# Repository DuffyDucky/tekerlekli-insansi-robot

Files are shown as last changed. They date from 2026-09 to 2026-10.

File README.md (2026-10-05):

# Tekerlekli insansı robot — üniversite projesi

Manisa Celal Bayar Üniversitesi Mekatronik MYO'da 4 kişilik ekiple yapılacak, bacaksız, tekerlekle
hareket eden, gövde + kafa + 2 kollu insansı robot. Bu klasör projenin tek çalışma alanı: raporlar,
planlama, tasarım (CAD) ve ileride yazılım kodu burada tutulur.

## Klasör yapısı

| Klasör / dosya | İçerik |
|---|---|
| `raporlar/Humanoid-Robot-Fizibilite-Raporu.html` | Fizibilite raporu: maliyet, ses mi görüntü mü, yetkinlik, teknik gereklilikler, profesyonel destek, takvim, finansman, riskler |
| `raporlar/kaynaklar/` | Raporun dayandığı araştırma notları (donanım/maliyet, yazılım/yapay zekâ, referans projeler/finansman, parça ölçüleri, fiyat araştırması ve doğrulaması) |
| `planlama/proje-plani.md` | Kapsam, takvim, roller, ilk iki hafta, riskler, açık sorular |
| `planlama/maliyet.json` | Doğrulanmış malzeme maliyeti (satıcı, TL, bağlantı, stok); demodaki maliyet bölümünün tek kaynağı |
| `tasarim/Robot-Tasarim-Demosu.html` | Gerçek parçalarla 3B CAD montajı; V1 / V2 düğmesi; devrilme, motor ve servo hesabı canlı; TL + USD proje maliyeti |
| `tasarim/cad/Humanoid-Robot-Montaj.step` · `-V2` · `-V3` | SolidWorks'te açılan montaj dosyaları (V1, V2, V3) |
| `tasarim/cad/parca-listesi.csv` · `-V2` · `-V3` | Gerçek parça listesi (model, ölçü, adet, kütle) |
| `tasarim/cad/robot_cad.py` | Modeli üreten kod (STEP + CSV + demo) |
| `tasarim/cad/demo_uret.py` | Demoyu şablon + model + maliyetten yeniden üretir; CadQuery gerekmez |
| `CLAUDE.md` | Bu klasörde açılan yapay zekâ oturumları için bağlam |

HTML dosyaları çift tıklayınca tarayıcıda açılır. Demodaki 3B görünüm için internet gerekir.

## Proje çerçevesi (Duffy, 26 Eylül 2026)

- Ekip: **4 kişi**
- Süre: **normalde 1 dönem**, proje başarılı giderse muhtemelen 2 dönem
- Bütçe: **okul / hoca destekli**
- Karar verilmemiş: robot yalnız sesle mi etkileşsin, ses + görüntüyle mi

## Şu ana kadarki kararlar ve öneriler

| Konu | Öneri / sonuç |
|---|---|
| Ses mi görüntü mü | Önce ses + tekerlek + kayıtlı jestler. İkinci adım "hafif görüntü": yüzü algılayıp kafayı kişiye çevirme ve düğmeyle "ne görüyorsun?". Yüz **tanıma**, otonom gezinme (ROS 2 / Nav2), eşya tutan kol kapsam dışı. |
| Konuşma zinciri | Bulut konuşma tanıma (Türkçe) + bulut dil modeli + seslendirme; uyandırma kelimesi yerine bas-konuş düğmesi; internet kesilirse çevrimdışı yedek mod |
| Bütçe | CAD tasarımının doğrulanmış malzeme listesi (27 Eylül 2026): **≈ 64.500 TL ≈ 1.320 USD** (%15 pay, yedek parça ve kargo dahil); 54 kalemin 48'i satıcı sayfasından doğrulandı. Baskı hizmetiyle ≈ 68.800 TL. Aylık bulut ≈ 10–20 $. (Fizibilite tahmini ≈ 61.700 TL'ydi.) |
| Ekip | Yazılım / yapay zekâ sorumlusu şart; güç elektroniği ve KVKK için danışman |
| Güvenlik | LiPo yerine LiFePO4 akü, donanımsal acil stop, servo ve işlemci için ayrı güç hatları |
| Mekanik | Ağırlığı alta topla, tabanı geniş tut, robotu kat kat kur ve her katta test et |
| V2 (hoca, 2 Ekim 2026) | 10,1" dokunmatik ekran göğüste, kafada iki yuvarlak göz ekranı (Pepper benzeri; Duffy A seçeneğini seçti). Tekerlekler yerinde, taban kabuğu genişleyip onları sarıyor. Malzeme ≈ 77.900 TL (%15 pay dahil; V1 64.500). |
| V3 deneme (Duffy, 2 Ekim 2026) | V2 yorumu: "taban çok geniş", "ekran çok alçakta", "yüz ifadesi çok ruhsuz". V3: boy 125 cm, şase 27 cm (akünün sığdığı en dar), taban 44 cm ve yukarı 30 cm'ye daralan etek, 10,1" ekran üst göğüste 15° yukarı eğik (merkez 82 cm), kafada 7" yüz ekranı + siyah akrilik yüz paneli (Pi 5 iki HDMI). Malzeme ≈ 79.400 TL. |

## CAD modelinden çıkanlar (varsayılan tasarım)

| Konu | Sonuç |
|---|---|
| Ölçü | 48 × 52 × 115 cm (teker dahil genişlik × derinlik × boy) |
| Toplam kütle | 17,75 kg (0,6 kg vida/kablo payı dahil) |
| En ağır kalemler | 40×40 ağır sigma ≈ 5,3 kg · LiFePO4 akü 2,8 kg · PETG kabuklar ≈ 3,3 kg · alt plaka 1,3 kg |
| Ağırlık merkezi | yerden 291 mm, merkezin 17 mm gerisinde |
| Devrilme | ileri frende 6,8, geri frende 5,7 m/s² (acil stop payı 3,8×); yana 7,2 m/s² |
| Taban motoru | 4× JGB37, 5° rampada motor başına 4,7 kg·cm (sürekli sınırın %74'ü) |
| Kol | 386 g; omuz 5,4 kg·cm (DS3218 güvenli sınır 10), dirsek 1,0 kg·cm (MG996R sınır 5) |
| **V2 farkı** | Ölçü 51 × 52 × 115 cm · 18,9 kg · ağırlık merkezi 282 mm · devrilme ileri 6,9, geri 5,9 m/s² (pay 4,0×), yana 7,4 · motor 5,0 kg·cm (%79) · PETG ≈ 4,4 kg · taban kabuğu 513 × 227 × 520 (9 baskı parçası), gövde 6, kafa 2 · çakışma yok (kol × gövde 2.822 mm³ V1'den kalma) |
| **V3 farkı** | Ölçü 44 × 52 × 125 cm · 18,6 kg · ağırlık merkezi 337 mm · devrilme ileri 5,8, geri 5,0 m/s² (pay 3,3×), yana 5,2 (3,4×) · motor 4,9 kg·cm (%77) · PETG ≈ 4,4 kg · etek 6, gövde 8, kafa 2 baskı parçası · çakışma yok (kol × gövde 2.299 mm³, V1'den kalma sorun) |
| Yapı | 340×500 sigma çerçeve; altta 3 mm Al plaka + yatık akü (arka) + motor sürücüleri (ön); 40 mm burç üstünde 5 mm kontrplak elektronik katı; motorlar L braketle plaka altında; tek sigma direk + 200 mm omuz traversi; PETG kabuklar |

## Konuşma geçmişi (26 Eylül 2026)

1. **Fizibilite araştırması:** üç paralel araştırma (donanım-maliyet, yazılım-yapay zekâ, referans
   projeler-finansman-destek) → `raporlar/`. Ajan çıktılarında iki düzeltme yapıldı: 2 JGB37 motor
   15–20 kg'a yetmez (≤15 kg ya da 4 motor); LiPo yerine LiFePO4.
2. **Fiziksel yapı endişesi:** Duffy: "beni korkutan fiziksel yapısı". Yaklaşım: robot aslında
   "insan gibi görünen bir servis arabası"; ağırlık alta, katman katman yapım ve test.
3. **Tasarım demosu v1:** basit kutularla 3B model, kaydırıcılarla devrilme/motor/servo hesabı.
4. **Gerçek parçalarla CAD (v2):** Duffy: "buna reel bir görünüm kazandır kullanacağın parçalar
   gerçek olsun hatta solid gibi bir yerde çiz". Bilgisayarda CAD programı olmadığı için CadQuery
   ile gerçek ölçülü montaj kuruldu; 19 parçanın ölçüsü araştırıldı (12'si üretici çiziminden) →
   `raporlar/kaynaklar/04-parca-olculeri.md`. STEP dosyası geri okuma testinden geçti (218 geçerli katı).
5. **Taşıma:** proje DuffyOS vault'undan bu klasöre taşındı; bundan sonraki çalışmalar burada.

## Açık işler

- [ ] Robotun amacını hocayla netleştir (karşılama / tanıtım / rehber) → kapsam ve malzeme listesi kesinleşir
- [ ] İşletmede Mesleki Eğitim (4. yarıyıl, 2027 bahar) projenin 2. dönemini daraltır mı? Bölüme sor
- [ ] Rolleri yaz; yazılım sorumlusu yoksa bilgisayar mühendisliğinden ortak ara
- [ ] Bölümde hazır malzemeyi listele (3D yazıcı, dizüstü, profil, güç kaynağı)
- [ ] Siparişi erken ver: 27 Eylül'de enkoderli JGB37 yalnız Direnc.net'te stokta; Camera Module 3 Türkiye'de hiçbir satıcıda yok (stok alarmı ya da Adafruit)
- [ ] Limacell 24 Ah akünün ölçüsünü satıcıya sor (CAD yuvası 181 × 77 × 167 mm)
- [ ] Lazer kesim (Al plaka, kontrplak) için DXF ile online teklif al; tahmini 2.000 TL
- [ ] JGB37 braketini alırken delik düzenini kontrol et (mil 7 mm kaçık; çoğu satıcı ortalı mil braketi satıyor)
- [ ] STEP dosyasını SolidWorks'te aç (henüz denenmedi)
- [ ] Parçalar gelince tahmini ölçüleri kumpasla doğrula (enkoder boyu, braket delikleri, BTS7960 delikleri)
- [ ] Ağırlık için hafif profil (40×40 hafif veya 30×30) seçeneğini değerlendir (≈ 2 kg, tahmini)
- [x] Hoca geri bildirimi (2 Ekim 2026): (1) ekran daha büyük olsun (şu an 7"); (2) tekerlekler dışarıda
  değil, kabuğun içine gömülü olsun. Hoca: ekran gövdede de olabilir. Karar (Duffy): tekerlekler yerinde kalır,
  kabuk dışa genişleyip tekerlekleri sarar; yüz A seçeneği (göğüste ekran + kafada göz ekranları). → Demoda V2.
  SolidWorks tasarımında da uygulanacak.
- [ ] V2 kabuklarının 23 cm'lik baskı bölme çizgileri ve birleşme yerleri (SolidWorks'te)
- [ ] 10,1" ekranın 5 V ≈ 0,75 A beslemesini güç planına ekle; ekran ve göz ekranı kütlelerini tartıp CAD'e gir
- [ ] Okulun 3D yazıcı tablası 25 × 25 × 25 cm (hocanın söylediği; model doğrulanmadı). Her baskı parçası
  buna sığacak şekilde bölünmeli (pay için ≤ 23 cm hedef)

## CAD'i yeniden üretme

`tasarim/cad/robot_cad.py` başındaki ölçü ve yerleşim değerleri değiştirilip çalıştırılınca STEP,
parça listesi ve demo birlikte yenilenir. Python 3.12 + CadQuery 2.8 gerekir (`requirements.txt`).
Sanal ortamı OneDrive dışında kur (yüzlerce MB):

```powershell
uv venv --python 3.12 $env:LOCALAPPDATA\robot-cad-venv
uv pip install --python $env:LOCALAPPDATA\robot-cad-venv\Scripts\python.exe -r tasarim\cad\requirements.txt
cd tasarim\cad
& $env:LOCALAPPDATA\robot-cad-venv\Scripts\python.exe robot_cad.py . model.json
```

Koordinatlar SolidWorks ile aynı: Y yukarı, Z ileri (robotun yüzü +Z), X sağ-sol, birim mm.

Yalnız fiyat ya da demo arayüzü değiştiyse CadQuery gerekmez: `planlama/maliyet.json` veya
`tasarim/cad/viewer-template.html` düzenlendikten sonra `python tasarim\cad\demo_uret.py` demoyu yeniler
(3B modeli mevcut demodan alır).

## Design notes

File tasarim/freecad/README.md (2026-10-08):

# FreeCAD modelleri (V3)

Robotun FreeCAD 1.1 modeli modül modül kuruluyor. Her modül kendi klasöründe, Python betikleriyle üretiliyor.
Üretilmiş dosyaları (FCStd, STEP, JSON, görseller, rapor.html) elle düzenleme; betiği değiştirip yeniden çalıştır.
Eski CadQuery modeli `tasarim/cad/robot_cad.py` yalnız ölçü kaynağı olarak okunuyor.

## Klasör düzeni

| Dosya / klasör | Rol |
|---|---|
| `arayuz.py` | **Tek ölçü ve arayüz kaynağı** (saf Python, FreeCAD'siz import edilir): global koordinat, V3 ana ölçüleri (robot_cad satırıyla), sigma profil özellikleri, cıvata/pul/somun/çekiç somun tabloları, köşe bağlantı ölçüleri, modül yerleşimleri (`MODULLER`), ayrılmış bölgeler (`BOLGELER`) |
| `ortak_lib.py` | Ortak parça kütüphanesi: `box/cyl/hexprism`, DIN 912/913/934/985/125, ısıl gömme somun, çekiç somun, rulman, sigma (X/Y/Z), 40×40 geniş köşe bağlantı, iç köşe bağlantı, `yerlestir()` |
| `sigma_profil.py` | 40×40 ağır sigma kesiti (kesit alanı üreticiye göre doğrulandı); doğrudan çalışınca test parçası üretir |
| `omuz/` | Sağ omuz (2 eksen): `omuz_parcalar.py` parçalar + kinematik, `omuz_montaj.py` kontroller + kayıt, `omuz_gorsel.py`, `omuz_rapor.py`, `omuz_regresyon.py` |
| `iskelet/` | Şase çerçevesi + gövde direği + omuz traversi + bağlantılar: `iskelet_parcalar.py`, `iskelet_montaj.py`, `iskelet_gorsel.py`, `iskelet_rapor.py` → `rapor.html`, `iskelet_regresyon.py` |
| `kabuk/` | Gövde kabuğu + taban eteği + Nextion göğüs ekranı + iskelete bağlantı braketleri: `kabuk_lib.py`, `kabuk_parcalar.py`, `kabuk_montaj.py` (kontroller, baskı analizi), `kabuk_gorsel.py`, `kabuk_rapor.py` → `rapor.html` |
| `dirsek/` | Sağ dirsek + ön kol + bilek + el (sol = X aynası): `dirsek_lib.py` (MG996R, horn, baskı analizi), `dirsek_parcalar.py`, `dirsek_montaj.py` (kontroller, dirsek içi tarama, tork, baskı), `dirsek_gorsel.py`, `dirsek_rapor.py` → `rapor.html`, `dirsek-analiz.json`. Arayüz `arayuz.DIRSEK`; modüller arası tarama `carpisma.py` (kol zinciri), ana montajda `dirsek_sag` / `dirsek_sol` |
| `kafa/` | Boyun + pan + tilt + kafa: `kafa_lib.py` (6808-2RS, 7" LCD, Camera Module 3, baskı analizi), `kafa_parcalar.py`, `kafa_montaj.py` (kontroller, pan × tilt tarama, R62 uyumu, tork, baskı), `kafa_gorsel.py`, `kafa_rapor.py` → `rapor.html`, `kafa-analiz.json`. Arayüz `arayuz.KAFA`, `MODULLER['kafa']`; modüller arası tarama `carpisma.py` bölüm 4b, ana montajda `kafa` (pan + tilt) |
| `taban/` | Alt plaka + elektronik katı (ön) + güç paneli (arka) + 4 motorlu tahrik + akü + güç elektroniği + kartlar + sonar + acil stop: `taban_lib.py`, `taban_parcalar.py`, `taban_montaj.py` (kontroller, iskelet/kabuk statik tarama, devrilme/motor/akü hesabı, DXF, baskı) → `taban-analiz.json`, `dxf/`; `taban_gorsel.py`, `taban_rapor.py` → `rapor.html`. Arayüz `arayuz.TABAN`, `MODULLER['taban']`; modüller arası tarama `carpisma.py` bölüm 4c, ana montajda `taban` (4 teker eklemi) |
| `montaj/` | **Ana montaj** (FreeCAD Assembly): iskelet + sağ/sol omuz + kabuk + sağ/sol dirsek + kafa + taban (tam robot) tek dosyada (sol = gerçek aynalı geometri), eklemler, eklem doğrulaması → `robot-montaj.FCStd`, `rapor.html` |
| `carpisma.py` | Modüller arası çakışma: modülleri `arayuz.MODULLER` ile yerleştirir, ev pozunu, hareketli modüllerin tüm tarama pozlarını, kol zincirini (omuz × dirsek × bilek; iki kol birbirine karşı), kafayı (pan × tilt × iki kolun pozları), tabanı (ev pozu, iki kolun tüm pozları, kafa) ve henüz çizilmemiş modüllerin ayrılmış bölgelerini (artık yok) tarar. **Bölümlü:** `CARPISMA_BOLUM` ile bölüm seçilir, her bölüm `carpisma-bolum/<bolum>.json`'a yazar |
| `carpisma_kos.py` | Bölümlü koşu sürücüsü (sistem Python'u): bölümleri sırayla ayrı `freecadcmd` süreçlerinde koşar (bellek her bölümden sonra boşalır), sonunda birleştirir → `carpisma-sonuc.json` (`bolumler`: süre, tepe bellek; `birlestirme_notu`, `tek_kosu`) |
| `OZET.md` | Tüm robotun tek sayfalık özeti: modüller, sayılar, kütle/AM, devrilme, motor, akü, yazılım sınırları, açık işler |

Koordinat (global): orijin zemin + robot merkezi, +X robotun sağı, +Y yukarı, +Z ileri (yüz), mm.
Her modülün yerel orijini `arayuz.MODULLER`'de (sağ omuz = travers merkezi (0, 955, 0); sol omuz = sağın X aynası).

## Çalıştırma

`freecadcmd`, yolunda "ü" (Masaüstü) olan betiği doğrudan alınca çöküyor. Betikler ASCII yoldaki başlatıcıyla çalışır
(`C:\Users\Victus\.robot-cad\run_fc.py`, hedef betik `FC_SCRIPT` ortam değişkeninde). Konsol çıktısı ASCII.

```bash
FC="$LOCALAPPDATA/Programs/FreeCAD 1.1/bin/freecadcmd.exe"   # GUI gerektirenler için freecad.exe
R="C:/Users/Victus/OneDrive/Masaüstü/Robot/tasarim/freecad"
L=C:/Users/Victus/.robot-cad/run_fc.py

# iskelet: montaj + kontroller + eğilme + STEP/BOM/JSON (~15 s), görseller (GUI), rapor (sistem Python'u)
FC_SCRIPT=$R/iskelet/iskelet_montaj.py "$FC" $L
FC_SCRIPT=$R/iskelet/iskelet_gorsel.py "$LOCALAPPDATA/Programs/FreeCAD 1.1/bin/freecad.exe" $L
python $R/carpisma_kos.py                             # modüller arası tarama: 9 bölüm sırayla, ayrı süreçlerde (~1,5 saat) -> carpisma-sonuc.json
python $R/carpisma_kos.py kafa_sag kafa_sol           # yalnız seçilen bölümler + birleştirme (diğerleri eski dosyalarından; not 'tek_kosu: false')
python $R/carpisma_kos.py birlestir                   # yalnız birleştirme (carpisma-bolum/*.json -> carpisma-sonuc.json)
FC_SCRIPT=$R/carpisma.py CARPISMA_BOLUM=taban "$FC" $L   # tek bölüm elle (statik|omuz|kol_sag|kol_sol|kolkol|kafa_sabit|kafa_sag|kafa_sol|taban;
                                                         # kol, kafa, hepsi kısaltmaları); günlükler %TEMP%/carpisma-<bolum>.log
# CARPISMA_KISA=1: kafa x kol taramasını yasak bölge çevresine daraltan geliştirme testi (carpisma-bolum/<bolum>-kisa.json, birleştirmeye girmez)
python $R/iskelet/iskelet_rapor.py                     # iskelet/rapor.html

# omuz: montaj + tarama + tork (~40 s), görseller, rapor
FC_SCRIPT=$R/omuz/omuz_montaj.py "$FC" $L
FC_SCRIPT=$R/omuz/omuz_gorsel.py "$LOCALAPPDATA/Programs/FreeCAD 1.1/bin/freecad.exe" $L
python $R/omuz/omuz_rapor.py

# omuz regresyonu: ortak dosyalar (arayuz, ortak_lib, sigma_profil) değişince omuzun aynı kaldığını kanıtlar
FC_SCRIPT=$R/omuz/omuz_regresyon.py REG_ETIKET=sonra "$FC" $L   # omuz/regresyon/once.json ile karşılaştırır -> fark.json
# iskelet regresyonu (dosya yazmaz, yalnız iskelet_parcalar'ı import eder): değişiklikten önce once, sonra sonra
FC_SCRIPT=$R/iskelet/iskelet_regresyon.py REG_ETIKET=sonra "$FC" $L   # iskelet/regresyon/fark.json

# kabuk: parçalar + kontroller + baskı analizi + STEP/BOM/JSON (~6 dk), görseller (GUI), rapor
FC_SCRIPT=$R/kabuk/kabuk_montaj.py "$FC" $L
FC_SCRIPT=$R/kabuk/kabuk_gorsel.py "$LOCALAPPDATA/Programs/FreeCAD 1.1/bin/freecad.exe" $L
python $R/kabuk/kabuk_rapor.py                 # carpisma.py ve ana montajdan sonra (onların sonuçlarını da okur)
# dirsek: montaj + kontroller + tarama + tork + baski (~30 s), gorseller (GUI), rapor
FC_SCRIPT=$R/dirsek/dirsek_montaj.py "$FC" $L
FC_SCRIPT=$R/dirsek/dirsek_gorsel.py "$LOCALAPPDATA/Programs/FreeCAD 1.1/bin/freecad.exe" $L
python $R/dirsek/dirsek_rapor.py
# kafa: montaj + kontroller + pan x tilt tarama + tork + baski (~2 dk), gorseller (GUI), rapor
FC_SCRIPT=$R/kafa/kafa_montaj.py "$FC" $L
FC_SCRIPT=$R/kafa/kafa_gorsel.py "$LOCALAPPDATA/Programs/FreeCAD 1.1/bin/freecad.exe" $L
python $R/kafa/kafa_rapor.py
# taban: parcalar + kontroller + iskelet/kabuk statik tarama + hesaplar + DXF + baski (~2 dk), gorseller (GUI), rapor
FC_SCRIPT=$R/taban/taban_montaj.py "$FC" $L
FC_SCRIPT=$R/taban/taban_gorsel.py "$LOCALAPPDATA/Programs/FreeCAD 1.1/bin/freecad.exe" $L
python $R/taban/taban_rapor.py
```

Not: `omuz_regresyon.py` `omuz_montaj.py`'yi çalıştırıp omuz çıktılarını yeniden yazar (FCStd GUI durumu kaybolur). Sonuç birebir
aynıysa üretilmiş omuz dosyaları `git checkout` ile geri alınabilir.

PowerShell'de: `$env:FC_SCRIPT="<betik>"; & "$env:LOCALAPPDATA\Programs\FreeCAD 1.1\bin\freecadcmd.exe" C:\Users\Victus\.robot-cad\run_fc.py`

Sıra: `arayuz.py` veya `ortak_lib.py` değişirse → omuz ve iskelet regresyonu → iskelet montajı → kabuk montajı → dirsek montajı → `carpisma.py` →
`carpisma_kos.py` → ana montaj (`ana_montaj.py` + `montaj_gorsel.py` + `montaj_gui_kontrol.py` + `eklem_dogrulama.py`) → görseller → raporlar
(`montaj_rapor.py`, `taban_rapor.py`, `kafa_rapor.py`, `kabuk_rapor.py`, `dirsek_rapor.py`; hepsi `carpisma-sonuc.json` ve montaj çıktılarını okur).

## Ana montaj (`montaj/`)

Tüm modüller tek FreeCAD Assembly dosyasında: `robot-montaj.FCStd` (+ `robot-montaj.step`). Modül listesi ve yükleyiciler
`montaj/moduller.py`'de (`SIRA` + `MODUL_YUKLE`); yerleşim yalnız `arayuz.MODULLER`'den okunur, sol omuz şekil aynalanarak
(gerçek aynalı geometri, parça adları "(sol)") kurulur; sol dirsek de aynı yolla. Eklemler: iskelet zemine sabit, her omuz gövdesi ve kabuk iskelete sabit, her omuzda
öne-arka (S1, −45…135°) ve yana açma (S2, 0…120°) döner eklemi. Her dirsek çatalı omuzun Kol grubuna sabit
(üst kol tüpü ucu), her kolda dirsek (0…105°) ve bilek (−90…90°) döner eklemi; eksen ve sınırlar `dirsek/dirsek-montaj.FCStd`'den okunup
`arayuz.DIRSEK` ile karşılaştırılır. Kafanın sabit boynu (Kafa_Govde) traverse sabit; pan (Kafa_Govde → Kafa_Boyun, −90…90°) ve tilt
(Kafa_Boyun → Kafa_Bas, −25…30°) döner eklemleri `kafa/kafa-montaj.FCStd`'den (etiketle: dosyada pan eklemi "Pan001") okunup `arayuz.KAFA` ile
karşılaştırılır; kablo demeti gösterimi ana montajda yok. Dirsek yükleyicisinde `ust_kol` (zincir: beklenen poz omuz açılarını da alır) ve `analiz` (analiz JSON yolu) var. Eksen ve sınırlar `omuz/omuz-montaj.FCStd`'den okunur.

```bash
M=$R/montaj
FC_SCRIPT=$M/ana_montaj.py "$FC" $L          # montaj + STEP + montaj-analiz.json (parça/kütle/AM modül toplamıyla karşılaştırılır)
FC_SCRIPT=$M/montaj_gorsel.py "$LOCALAPPDATA/Programs/FreeCAD 1.1/bin/freecad.exe" $L   # eklem görünümleri + Kollari_oynat simülasyonu, dosyayı GUI'den kaydeder; görseller; GIF kareleri %TEMP%/robot-montaj-kare
FC_SCRIPT=$M/montaj_gui_kontrol.py "$LOCALAPPDATA/Programs/FreeCAD 1.1/bin/freecad.exe" $L   # taze açılış: eklem görünür/seçilebilir, fareyle sürükleme -> gui-kontrol.json
FC_SCRIPT=$M/eklem_dogrulama.py "$FC" $L      # eklemleri simülasyonla sürer, omuz kinematiğiyle karşılaştırır -> eklem-dogrulama.json
python $M/montaj_rapor.py                      # GIF + montaj/rapor.html
```

- `ana_montaj.py` tek başına çalışırsa dosyada eklem görünüm nesneleri olmaz; ardından `montaj_gorsel.py` şart.
- FreeCAD 1.1'de eklem sınırları yalnız fareyle sürüklemede uygulanır; simülasyon ve `solve()` sınır dışı açıyı kabul eder.
- Ana montajda bir parçanın şekli kendi Placement'ını taşıyabilir (kafa parçaları): dosyadan AM hesabında yalnız üst grubun yerleşimi uygulanır.
- Taban: gövde grubu (`Taban_Govde`) uzun raya sabit; 4 teker grubu (`Taban_OnSagTeker` …: teker + kaplin + M4 eksenel vida + pul)
  gövdeye **sınırsız** döner eklemle (`Taban_TekerOnSag` …; eksen motor mili +X, teker merkezi x ±178, y 62,5, z ±185; pozitif = ileri
  yuvarlanma). `taban-montaj.FCStd`'de eklem yok; eksen `taban_parcalar` (X_WH, Z_WH, arayuz.AX) ile `moduller.yukle_taban`'da kurulur.
  Grup adları eklem adlarıyla çakışmamalı (FreeCAD aynı adlı nesneye "001" ekler).
- Yeni modül: `arayuz.MODULLER`'e yerleşim, `moduller.py`'ye yükleyici (parçalar, gruplar, bağlantı, eklemler (sınır `None` = sınırsız),
  beklenen poz) ve `SIRA`'ya ad. Hareketli modülün beklenen pozu `eklem_dogrulama.py`'de karşılaştırılır.

## Kontroller

| Kontrol | Nerede | Ölçüt |
|---|---|---|
| Parça geçerliliği | her `*_montaj.py` | `isValid()` ve tek katı |
| Modül içi çakışma | her `*_montaj.py` | tüm çiftler, `common().Volume > 0,5 mm³` çakışma |
| Bağlantı oturması | `iskelet_montaj.py` | köşe bağlantı ve kama profile dayalı, çekiç somun dudak altında, cıvata ucu somunu geçip kanal tabanına değmiyor, set vida tabana dayalı |
| Ayrılmış bölgeler | `iskelet_montaj.py`, `carpisma.py` | henüz çizilmemiş modüllerin bölgelerine taşma yok |
| Modüller arası | `carpisma.py` (bölümlü, `carpisma_kos.py`) | ev pozu + her hareketli modülün tüm tarama pozları; kol zinciri (omuz −45…135 / 0…120 × dirsek 0…105 × bilek ±90, kaba 15° + 5 mm altında ince 5°, aralık dışı halka ayrı) iskelet, kabuk, bölgeler, omuz gövde/göbeğine karşı; iki kol birbirine karşı (simetrik, zıt, birlikte öne); kafa (pan −180…165 × tilt −25…40, kaba 15°) sabit modüllere ve iki kolun 1770'er pozuna karşı (sıkı tessellation kutusu ön elemesi, 5 mm altı / çakışma çevresi 5° ince; yasak bölge sınırı çakışan çiftlerin eksen komşularıyla yakınsayana dek); taban: ev pozunda tüm modüllere (çakışma, temas, en küçük boşluk), iki kolun tüm pozlarına (acil stop, sonar, ana anahtar, etek), kafaya (sınır kutusu) |
| Ana montaj | `montaj/ana_montaj.py`, `montaj/eklem_dogrulama.py` | parça sayısı/kütle/AM = modül toplamı; simülasyonla sürülen eklemlerde çözücü konumu = modül kinematiği |
| Regresyon | `omuz/omuz_regresyon.py`, `iskelet/iskelet_regresyon.py` (+ `taban/regresyon/moduller.json`: kabuk/dirsek/kafa çıktıları önceki ve güncel `arayuz.py` ile) | parça sayısı, hacim, sınır kutusu, kütle, AM, çakışma, tarama/tork (omuz), bağlantılar (iskelet) birebir |
| Kabuk bağlantıları | `kabuk/kabuk_montaj.py` | braket profile ve boss'a dayalı, çekiç somun dudak altında, M6 ucu somunu geçip kanal tabanına değmiyor, eksen hizası; M5/M3 kavrama ≥ d ve ≤ ısıl gömme somun deliği, dış yüzeye ≥ 1 mm et; bindirme cıvatası başı dudağa, ısıl gömme somun boss'a oturmuş |
| Baskı | `kabuk/kabuk_montaj.py` | her baskı parçası `arayuz.YAZICI` kullanılabilir hacmine sığar; 45° üstü çıkıntı oranı; 1 mm katmanlarla desteksiz basılabilirlik (2 mm'den dar şerit ve 15 mm'den kısa açıklık serbest) |

## Yeni modül eklemek (taban, kabuk, kafa, dirsek)

1. Ölçüleri ve yerleşimi `arayuz.py`'ye yaz (`MODULLER`'e yerel orijin; kendi ayrılmış bölgelerini `BOLGELER`'e).
2. Klasörü `iskelet/` gibi kur: `<modul>_parcalar.py` (import edilebilir, `P` listesi) + `<modul>_montaj.py` (kontroller + kayıt).
   Genel elemanları `ortak_lib.py`'den al; modüle özgü parçalar `<modul>_lib.py`'de kalsın.
3. `carpisma.py` içinde `MODUL_YUKLE`'ye bir yükleyici ekle ve adı `KONTROL` listesine koy. Hareketli modülde
   `hareket` (pozlar + grup yerleşimi) ver; başka modülün parçası olan parçaları `haric` listesine yaz. Modül çizilince
   o modülün `BOLGELER` kutuları otomatik olarak kontrol dışı kalır, yerine gerçek geometrisi taranır.

## Kabuk modülü (`kabuk/`)

Gövde kabuğu (4 yatay bant × sağ/sol + arka servis kapağı) ve taban eteği (3 bant × sağ/sol): 15 PETG baskı parçası, 3 mm duvar,
Bambu Lab X2D'ye (`arayuz.YAZICI`, kullanılabilir 246 × 246 × 250) sığacak şekilde bölünmüş. Biçim V3 `torso_shell3` / `base_cover3`
ölçüleriyle (`arayuz.GOVDE_KESIT`, `ETEK_KESIT`): yuvarlatılmış dikdörtgen kesitler, omuzda x = 147…152 düz yan duvar ve Ø84 delik
(omuz modülündeki referansla aynı), göğüste 15° eğik ön duvar ve Nextion NX1060P101_011 penceresi (`arayuz.NEXTION`, datasheet).

- **Bölme:** dış ve iç zarfın arasındaki orta zarf duvarı iki yarıya ayırır; iç yarının hücre sınırı dikişten 12 mm kaydırılınca bindirme
  dili oluşur (`kabuk_parcalar.py` baş notu). Dilde damla boss + M3 ısıl gömme somun, dudaktan M3×6 ISO 7380. Yatay plakalarda alın birleşim.
- **İskelete bağlantı:** 4 gövde braketi (3 mm Al U, direk ±X kanalına 2× M6 + çekiç somun, kabuğa M5 + ısıl gömme somun), 6 etek
  braketi (2 mm Al L, uzun ray üst kanalına M6, eteğe M3). Ölçüler `arayuz.KABUK_GOVDE_BRAKET` / `KABUK_ETEK_BRAKET`.
- **Ayrılmış bölgeler:** etek braketleri artık kabuk bölgesi; taban için sonar (3) ve acil stop (gövde, mantar) bölgeleri; Nextion konnektör
  ve kablo boşluğu (kabuk).
- **Baskı yönü** parça başına `kabuk_parcalar.BASKI`; boss'lar ve omuz deliği o yöne göre 45° damla şekilli.
- **Montajda:** `moduller.py`'de `kabuk` (tek grup, direğe sabit eklem); `carpisma.py`'de `KONTROL` listesinde. Tarama çıktısında hedef modül
  başına eklem aralığındaki en küçük boşluk (`modul_bosluk_eklem_araliginda`) ve çakışan pozlar (`modul_cakisan_poz`) var.

## Dirsek modülü (`dirsek/`)

Sağ kol: dirsek çatalı (üst kol tüpüne pim + sıkma bileziği) + ön kol (dirsek ve bilek MG996R) + bilek flanşı + sabit kancalı el; sol kol X aynası.
Ayrıntı ve sonuçlar `dirsek/rapor.html`'de.

- **Kol zinciri taraması** (`carpisma.py` bölüm 4): dirsek parçaları omuzla birlikte sürülür (çatal = Pp·Pr, ön kol ·Pe, el ·Pb). Sınır kutusu
  ön elemesi (köşeleri poz matrisiyle taşınan tutucu kutu, numpy), 5 mm altındaki her aday tam ölçülür, hedef başına en küçük boşluk dal-sınırla;
  5 mm altında kalan alt pozların çevresi 5° adımla yeniden taranır. Kol başına 1755 poz + 279 aralık dışı, iki kol ~10 dk.
- **Sonuç (8 Ekim 2026):** eklem aralığında çakışma 0, yasak poz bölgesi yok; kabuğa en az ~3,8 mm (kol aşağıda, çatal bileziği ↔ göğüs bandı),
  iskelete ~103 mm, iki kol arası ≥ 290 mm. Aralık dışı: yana −10°'de el kabuğa giriyor (omuz yana sınırı 0° engelliyor).
- **Tork kararı:** ana senaryo yüksüz jest (1. dönem kapsamı); mevcut servolar yeterli, 0,5 kg yük bilgi amaçlı, el ucu yükü ~50 g ile sınırlı.

## Kafa modülü (`kafa/`)

Boyun (traverse sabit: boyun plakası, servo yuvası, iki 6808-2RS, pan MG996R) + pan grubu (boyun mili, eğme çatalı, tilt MG996R) + kafa (iskelet,
ön/arka kabuk, 7" LCD, Camera Module 3). Ayrıntı ve sonuçlar `kafa/rapor.html`'de.

- **Modüller arası tarama** (`carpisma.py` bölüm 4b, 8 Ekim 2026): kafa × sabit modüller çakışma 0; en küçük boşluk sabit boyun ↔ kabuk R62 halkası
  8,4 mm, hareketli kafa ↔ iskelet 43 mm, ↔ omuz gövdesi 52 mm, ↔ kabuk 54 mm. Kafa × kollar: ön kola en az 25,7 mm, dirsek çatalına 55 mm, omuza 59 mm.
- **Yasak poz bölgesi (yazılım, 9 Ekim 2026 kesin sınır):** kol öne 125…135°, yana 0°, dirsek 70…105° (el yüzün önünde) iken kafa o kola
  doğru pan 30…55° (sol kolda −55…−30°) ve tilt 25…30° birlikte verilmemeli: el ön yüz kabuğuna giriyor (kol başına 198 yasak el alt pozu,
  603 çakışan poz çifti). Sınır, çakışan her çiftin eksen komşuları 5° (bilek 15°) adımla yeni çakışma kalmayana dek tarandı (8 turda
  yakınsadı); önceki ±5° belirsizlik giderildi (bölge önceki tahminden geniş: öne 125°, dirsek 70°, pan 55° de yasak). Satır satır tablo
  `kafa/rapor.html`'de (`yasak_kural`). Geometri değiştirilmedi.
- **Ana montaj:** 98 parça, 1.366,8 g (robot toplamı aşağıda, `## Taban modülü`). Eklem doğrulaması pan/tilt en büyük sapma
  2·10⁻¹⁰ mm. GUI: tilt kafadan sürükleniyor (30°'de duruyor), pan yalnız boyun milinden ve zor (−14…+3°).

## Taban modülü (`taban/`)

Alt plaka + ön elektronik katı + arka güç paneli + 4 JGB37 tahrik + LiFePO4 akü + güç elektroniği + kartlar + 3 sonar + acil stop: 306 parça
(3 lazer, 4 baskı) + 13 Referans (kablo yolu şemaları, ana anahtar düğmesi gösterimi), 7.508 g. Ayrıntı `taban/rapor.html`.

- **Modüller arası tarama** (`carpisma.py` bölüm 4c, 8 Ekim 2026): ev pozunda taban ↔ tüm modüller çakışma 0 (iskelet 44 temas: plaka/raylar,
  kabuk 1 temas: acil stop bileziği ↔ etek). Kollar × taban (her kol 1755 + 279 aralık dışı + 15 jest pozu, tüm alt pozlar, ana anahtar düğmesi
  ve etek dahil): çakışma 0, en küçük boşluk ~365 mm (el ↔ etek üstü), acil stop mantarına ~367 mm, sonara ~544 mm; kolun en alt noktası
  y ≈ 626 mm, tabanın en üstü y 290 mm. Kafa × taban: kafa en alt y 965 mm, taban en üst 290 mm (675 mm; ölçüm gerekmedi). Taban için yazılım
  sınırı ya da geometri değişikliği gerekmedi.
- **Ana montaj:** tam robot 907 parça, 22 grup, 22 eklem (14 döner: 2 × 4 kol, 2 kafa, 4 teker), **21.260,9 g**, AM (−0,4; 374,6; −13,5) mm.
  Kablo payı 400 g (tahmini, parça listesinde yok) eklenince 21.660,9 g, AM (−0,4; 370,5; −14,4): taban raporunun devrilme hesabıyla aynı
  (fark 0,0 g, 0,03 mm). Teker eklemleri sınırsız; eklem doğrulaması (400°, −720° dahil) en büyük sapma 1·10⁻¹⁰ mm, yön doğru (+90° → alt
  nokta geri = ileri yuvarlanma). GUI: 907/907 parça, 22 eklem görünür ve seçilebilir.
- **Bölümlü tam koşu (8 Ekim 2026, 22:17–23:44, tek koşu):** statik 55 s, omuz 1.733 s, kol sağ/sol 341/332 s, kol-kol 34 s, kafa × sabit 53 s,
  kafa × sağ/sol kol 1.104/1.474 s, taban 104 s; tepe bellek en çok 647 MB (kafa bölümleri), bellek sorunu yok. Eklem aralığında toplam 1.206
  çakışma, hepsi kafa-kol yasak bölgesi (603 + 603 poz çifti); diğer tüm bölümlerde eklem aralığında 0.
- **Regresyon:** `arayuz.py`'ye taban eklendi (yalnız ekleme) → omuz ve iskelet regresyonu fark 0; kabuk/dirsek/kafa parça adları, hacim, sınır
  kutusu ve kütlesi git HEAD arayüzüyle birebir aynı (`taban/regresyon/moduller.json`).

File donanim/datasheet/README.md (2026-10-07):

# Elimizdeki parçaların datasheet'leri

Sadece elde olan parçalar burada. Yeni parça gelince eklenir. İndirme tarihi: 7 Ekim 2026.

| Parça | Dosya | Kaynak |
|---|---|---|
| Raspberry Pi 5 8GB | `raspberry-pi-5-product-brief.pdf` (özellikler) | https://datasheets.raspberrypi.com/rpi5/raspberry-pi-5-product-brief.pdf |
| | `raspberry-pi-5-mechanical-drawing.pdf` (ölçü, delikler) | https://datasheets.raspberrypi.com/rpi5/raspberry-pi-5-mechanical-drawing.pdf |
| | `pi5-step/rpi-5b_no_graphics.step` (3B model, CAD için) | https://datasheets.raspberrypi.com/rpi5/RaspberryPi5-step.zip |
| | `rp1-peripherals.pdf` (GPIO/UART çipi RP1) | https://datasheets.raspberrypi.com/rp1/rp1-peripherals.pdf |
| Nextion NX1060P101_011 (Intelligent, 10.1") | `NX1060P101-011C-I_dimension.pdf` (ölçü çizimi, R ve C sürümü ortak) | https://cdn.nextion.tech/wp-content/uploads/2022/03/NX1060P101-011C-I_dimension.pdf |
| | Elektrik özellikleri PDF değil, web sayfasında (aşağıda özet) | https://nextion.tech/datasheets/nx1060p101-011c-i/ |

Datasheet'i olmayanlar: 64 GB SD kart ve Pi adaptörü. Marka/model belli olunca eklenecek.

## Robot için önemli değerler

### Raspberry Pi 5
- Besleme: 5 V / 5 A, USB-C (Power Delivery destekli).
- Kart ölçüsü 85 × 56 mm, montaj delikleri 58 × 49 mm aralıklı, Ø2.7 (mekanik çizim).
- GPIO 3,3 V mantık seviyesinde. 5 V sinyal doğrudan bağlanmaz.
- Çalışma sıcaklığı 0–70 °C, kapalı kutuda havalandırma şart.

### Nextion NX1060P101_011
- Ekran 1024 × 600 IPS. Dış ölçü 258 × 152 mm, görünen alan 222,72 × 125,28 mm.
- Montaj delikleri 251,6 × 145,6 mm aralıklı. Kalınlık yaklaşık 9,8 mm + 1,6 mm PCB.
- Besleme: 5 V (4,75–6,5 V). %100 parlaklıkta 800 mA, uykuda 170 mA. Önerilen kaynak 5 V 2 A.
- Bağlantı: 4 pin 2,54 mm (GND, RX, TX, +5V). UART 2400–921600 baud.
- **Dikkat:** Datasheet TX çıkışını 3,0–5,0 V olarak veriyor. Pi'nin RX pini 3,3 V'tur, 5 V'a dayanıklı değildir.
  Nextion TX → Pi RX hattına gerilim bölücü (1 kΩ + 2 kΩ) ya da seviye dönüştürücü koy.
  Pi TX (3,3 V) → Nextion RX doğrudan bağlanabilir (RX giriş eşiği 3,0 V).
- Karttaki "ON TTL / OFF 232" seçicisi Pi için **TTL** konumunda olmalı.
- Arayüz Nextion Editor ile hazırlanır, microSD kartla ya da seri hattan yüklenir. USB yok.
- Dokunmatik tipi (C kapasitif / R dirençli) kutu etiketinden doğrulanacak.

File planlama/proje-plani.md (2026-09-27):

# Proje planı

Kaynak: `raporlar/Humanoid-Robot-Fizibilite-Raporu.html` (26 Eylül 2026). Tarihler güz dönemine göre;
rakamların çoğu tahmin, teklif ve bölüm onayıyla kesinleşecek.

## Kapsam

**1. dönem hedefi:** konuşan, tekerlekle gezen, kollarıyla kayıtlı jest yapan robot.
**Esnek hedef (yetişirse 1. dönem sonu, yoksa 2. dönem):** kamerayla yüzü algılayıp kafayı kişiye
çevirme, düğmeyle "ne görüyorsun?".
**Kapsam dışı:** yüz tanıma (kimlik), otonom gezinme (ROS 2 / Nav2), eşya tutan kol.

Kapsam 2. haftada yazılı olarak dondurulur; yeni fikirler 2. dönem listesine yazılır.

## Takvim (güz dönemi ≈ 15 hafta)

| Hafta | İş | Çıktı |
|---|---|---|
| 1–2 (29 Eyl – 12 Eki) | Rol dağılımı, hoca onayı, kapsam belgesi. SolidWorks'te yerleşim, tork ve devrilme hesabı. Malzeme listesi ve sipariş | Onaylı kapsam, sipariş |
| 3–5 | Paralel: masada konuşan düzenek (Pi + mikrofon + hoparlör) · taban şasi, motorlar, ESP32 hız kontrolü, kumandayla sürüş · güç dağıtımı ve acil stop | Üç alt sistem ayrı ayrı çalışıyor |
| **6** | **İlk uçtan uca sürüm:** konuşan kafa tabanın üstünde, kumandayla geziyor. Bundan sonra her hafta entegrasyon testi | Çalışan ilk robot |
| 7–10 | 3D baskı gövde ve kollar, jest kütüphanesi, yüz ekranı, davranış akışı, çevrimdışı yedek mod | Tam görünüşlü robot |
| 11–12 | Hafif görüntü (yetişirse) | Kişiye dönen kafa |
| **13–15** | Sağlamlaştırma: 3 senaryo × 20 deneme, yedek parça, demo kontrol listesi, rapor | Teslim / demo |
| 2. dönem | Görüntü modülünü olgunlaştırma, belki tek hazır kolla (SO-101) nesne tutma, Teknofest / TÜBİTAK 2209-A | Genişletme |

Kapasite (tahmini): 4 kişi × haftada ≈ 8 saat × 15 hafta ≈ 480 kişi-saat. Yazılım 150–220 saat,
mekanik + elektrik + montaj 150–250 saat → 1. aşama sığar, hafif görüntü sınırda.

## Roller

| Rol | Kim | İş |
|---|---|---|
| Mekanik + proje lideri | Duffy | Tasarım (SolidWorks), montaj, takvim, satın alma, hoca ve sponsor ilişkisi |
| Elektrik / elektronik | — | Akü, güç dağıtımı, motor sürücüleri, acil stop devresi |
| Yazılım / yapay zekâ | — (şart) | Konuşma zinciri, davranış akışı, sonra görüntü |
| Gömülü + test | — | ESP32 kodu, haftalık entegrasyon testleri, belgeler |

## Profesyonel destek

| Alan | Öneri |
|---|---|
| Güç elektroniği, akü güvenliği | Danışman şart (EEM hocası / öğrencisi) + hazır BMS'li LiFePO4 |
| Yapay zekâ / yazılım | Ekip ortağı şart |
| KVKK (kamera, ses) | Danışman hoca, üniversite KVKK birimi. Yüz algılama evet, tanıma hayır; kayıt yok; bilgilendirme levhası |
| 3D baskı, lazer kesim | Büyük parçalarda hizmet (orta parça 500–1.500 TL; lazer 2–5 TL/dk) |
| Mekanik tasarım, acil stop | Ekip içi (Duffy), hoca kontrolü |

## Finansman

Ana kaynak bölüm / hoca bütçesi ve eldeki malzeme. MCBÜ BAP hoca üzerinden. Sponsorluk hemen
denenebilir (Manisa OSB). TÜBİTAK 2209-A ve 2209-B takvimi bir döneme yetişmez, 2. dönem için.

## Riskler

| Risk | Önlem |
|---|---|
| Kapsam şişmesi | 2. haftada yazılı kapsam |
| Servolar yüzünden Pi'nin yeniden başlaması | Ayrı güç hatları, ortak toprak, kondansatör |
| Parça stoğu / kargo | İlk iki haftada sipariş, her kalem için ikinci satıcı |
| Demo günü internet ve gürültü | Mobil modem, çevrimdışı yedek mod, bas-konuş düğmesi |
| Devrilme, servo yetersizliği | CAD hesabı baskıdan önce; akü en altta |
| 2. dönemde staj | Bölüme sor; asıl hedefi 1. döneme göre kur |
| Yazılım sorumlusunun ayrılması | Ortak depo; ikinci kişi de konuşma zincirini çalıştırabilsin |

## İlk iki hafta

1. Robotun amacını hocayla netleştir (karşılama / tanıtım / rehber).
2. 4 kişinin rollerini yaz.
3. Bölümde hazır malzemeyi listele.
4. Tasarımı SolidWorks'e taşı (`tasarim/cad/Humanoid-Robot-Montaj.step`), ölçüleri gözden geçir.
5. Malzeme listesini kesinleştir (`tasarim/cad/parca-listesi.csv` + raporun bütçe tablosu), siparişi ver.
6. İşletmede Mesleki Eğitim takvimini bölüme sor.

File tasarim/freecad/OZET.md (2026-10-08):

# Robot özeti (FreeCAD V3, 9 Ekim 2026)

Tekerlekli insansı robot, tüm modüller çizildi ve tek montajda (`montaj/robot-montaj.FCStd`). Kaynak: modül `*-analiz.json`'ları,
`carpisma-sonuc.json` (bölümlü tek koşu, 8 Ekim 22:17–23:44), `montaj/montaj-analiz.json`. "Tahmini" yazan değerler ölçülmedi.
Koordinat: orijin zemin + robot merkezi, +X sağ, +Y yukarı, +Z ileri (mm).

## Modüller

| Modül | Parça | Baskı (PETG) | Lazer / kesim | Kütle | Not |
|---|---|---|---|---|---|
| İskelet | 59 | – | 7 sigma 40×40 kesimi (3 × 1 m stok) | 5.793 g | şase + gövde direği + omuz traversi |
| Omuz (sağ + sol) | 2 × 68 | 2 × 5 (sol aynalı basılır) | – | 2 × 464 g | 2 eksen, DS3218MG × 2 |
| Kabuk | 202 | 15 | – | 4.926 g | gövde + taban eteği + Nextion 10,1" |
| Dirsek + bilek + el (sağ + sol) | 2 × 53 | 2 × 4 | – | 2 × 370 g | MG996R × 2 |
| Kafa | 98 | 7 | – | 1.367 g | pan + tilt MG996R, 7" LCD, Camera Module 3 |
| Taban | 306 | 4 | 3 (Al 3 mm plaka, 2 × 5 mm kontrplak) | 7.508 g | 4 × JGB37, LiFePO4, güç, kartlar, 3 sonar, acil stop |
| **Toplam (ana montaj)** | **907** | **44** | **3 lazer + 7 profil** | **21.261 g** | + kablo payı 400 g (tahmini) = **21,66 kg** |

Ağırlık merkezi (ev pozu, kollar aşağıda): montaj (−0,4; 374,6; −13,5) mm; kablo payıyla (−0,4; 370,5; −14,4) mm, yerden 370 mm.
Montaj kütlesi + kablo payı = taban raporundaki 21.660,9 g (fark 0,0 g, AM 0,03 mm). Eklemler: 14 döner (2 kol × 4, kafa 2, teker 4) + 7 sabit + zemin.

## Devrilme, motor, akü (taban raporu)

- **Devrilme** (temas teker merkez düzlemleri x ±178, z ±185; fren 1,5 m/s², tahmini): ev pozunda devrilme eşiği ileri / geri / yana
  5,3 / 4,5 / 4,7 m/s² (pay 3,5× / 3,0× / 3,1×), statik devrilme eğimi 28° / 25° / 26°. Tüm yüksüz kol pozlarında en küçük pay ~2,9×;
  5° rampada ev pozu payı 2,9× / 2,4× / 2,6×. 1 kg yükle kollar önde ileri pay 2,9×.
- **Tahrik:** 4 × JGB37-520 12 V 60 dev/dk enkoderli, teker 125 × 58. Düz zeminde 0,5 m/s² ile tork %44; 5° rampada 0,5 m/s² ile 5,7 kg·cm =
  sürekli değerin (6,3 kg·cm) **%90**'ı; rampada ivme ≤ 0,25 m/s² ile %77. Hız ~0,39 m/s.
- **Servolar:** omuz S1/S2 DS3218MG yüksüz pay 2,5×; dirsek MG996R 6,1×; kafa tilt 2,1×, pan 3,6×. Ana senaryo yüksüz jest; el ucu yükü ~50 g.
- **Akü:** LiFePO4 12,8 V 24 Ah (307 Wh; model 20 Ah Landport ölçüsüyle). Tahmini çalışma: düşük yük (11 W) ~22 saat, orta (33 W) ~7,5 saat,
  yüksek (81 W) ~3 saat.

## Yazılım sınırları (robot yazılımında uygulanmalı; FreeCAD eklem sınırları yalnız fareyle sürüklemede tutuyor)

| Eklem | Sınır | Neden |
|---|---|---|
| Omuz öne-arka (S1) | −45…135° | DS3218MG 180°, horn kol aşağıdayken 45°'de; geometri −60…180° izin verir |
| Omuz yana açma (S2) | 0…120° | 0°'nin altında kol / el kabuğa çarpar (yana −10°'de el kabuğa giriyor) |
| Dirsek | 0…105° | MG996R, çatal dayanağı |
| Bilek | −90…90° | MG996R |
| Kafa pan | −90…90° | `arayuz.KAFA` (serbest aralık ±180) |
| Kafa tilt | −25…30° | `arayuz.KAFA` (serbest −25…40) |
| Teker | sınırsız | hız / ivme sınırı: rampada ≤ 0,25 m/s² önerilir |
| **Kafa-kol yasak bölgesi** | kol öne 125…135°, yana 0°, dirsek 70…105° iken kafa o kola doğru pan 30…55° (sol kol −55…−30°) **ve** tilt 25…30° birlikte verilmemeli | el ön yüz kabuğuna girer; sınır 5° kesinlikte (yakınsadı), yazılımda +1 adım pay; satır satır tablo `kafa/rapor.html` |

Sol kol servoları aynalı: aynı eklem açısı için sol servo komut işareti ters (tahmini; montajda doğrulanmalı).
Diğer tüm modül çiftlerinde eklem aralığında çakışma 0 (omuz, kol zinciri, kol ↔ kol en az 290 mm, kafa × sabit, taban). En dar yerler:
kol ↔ kabuk ~3,8 mm (kol aşağıda), sabit boyun ↔ kabuk R62 halkası 8,4 mm, kafa ↔ ön kol 25,7 mm, kol ↔ taban/etek ~365 mm.

## Açık işler

**Satın alınacak / BOM'a eklenecek:** 12 V 40 A röle + soket; ESP32 taşıyıcı (pertinaks + 2 × 15'li dişi header); M2,5 pirinç burç + vida
(Pi, PCA9685, BNO055); M4 ve M5 çekiç somun; M5×16 set vida; 25 mm cırt kayış (2); köpük bant; XT60 şarj girişi; 37 mm L motor braketi;
kamera için ~1 m FPC (elimizdeki 200 mm yetmez; Pi tabanda, kamera kafada); kafaya HDMI kablosu (taban → kafa yolu).

**Ölçülecek / doğrulanacak (kumpas, tartı, datasheet):** Limacell 24 Ah akünün ölçüsü, kütlesi ve kutup yeri (yuva 181 × 77 × 167); sigorta
kutusu, röle, ana anahtar ASW-A01, ana sigorta yuvası (tahmini zarflar); BTS7960 delik aralığı; eldeki BNO055 muadili; HC-SR04 pin bloğu;
motor braketi delik düzeni (flanş x 115 hizası); servo horn delik dizilimi (omuz, dirsek); köşe bağlantı ve çekiç somun ölçüleri (iskelet);
Nextion ölçüleri; ısıl gömme somun ölçüleri; LCD kütlesi ve kamera delikleri; 6808-2RS / 625ZZ yük değerleri.

**Tasarım kararları bekleyen:** kabuk etek üst plakasına ana anahtar deliği ve XT60 şarj girişi; etekte ısı (Pi 5 + 3 × XL4016 + 2 × BTS7960)
ölçülüp gerekirse havalandırma; rampada motor torku (%90) için yazılım ivme sınırı ya da daha güçlü motor; 270° servo alınırsa omuz sınırları
genişletilebilir; tilt servosunda radyal yük (ikinci rulman seçeneği).

Ayrıntı: `montaj/rapor.html` (tam robot), modül raporları `iskelet/ omuz/ kabuk/ dirsek/ kafa/ taban/rapor.html`; çalıştırma `README.md`.

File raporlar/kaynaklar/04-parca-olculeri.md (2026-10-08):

---
title: "Kanıt: Gerçek parça ölçüleri (CAD için)"
created: 2026-09-26
---

> Claude Opus alt ajan raporu, 26 Eylül 2026. Parça tabloları kısaltıldı; değerler, kaynaklar ve güven işaretleri rapordaki gibi. Bu değerler `tasarim/cad/robot_cad.py` başındaki ölçü tablosuna işlendi.
> Özet: 19 parçadan 12'si üretici çiziminden doğrulandı (Pi 5, Active Cooler, Camera Module 3, Waveshare 7", ESP32-DevKitC, DS3218, MG996R, PCA9685, Emas B200E60, sigma kesiti, köşe bağlantı, Adafruit kartları); diğerleri satıcı verisi. "Tahmini" değerler parça gelince kumpasla ölçülmeli.

| Parça | Ana ölçüler (mm) | Güven | Kaynak |
|---|---|---|---|
| JGB37-520 enkoderli | Redüktör Ø37; boy oranla değişir: 1:56–90 → 24, ≥1:131 → 26,5 · motor Ø33 × 22 · enkoder ~Ø33–35 × 17–20 (tahmini) · mil Ø6 D (düzlük 5,5) × 15, **7 mm kaçık** · ön yüz 6× M3, Ø31 daire | satıcı / tahmini-orta | https://probots.co.in/jgb37-520-dc12v-320-rpm-miniature-speed-reduction-gear-dc-motor.html · https://probots.co.in/jgb37-520-dc12v-7-rpm-miniature-speed-reduction-gear-dc-motor.html · https://www.hotmcu.com/encoder-geared-motor-aslongjgb37520%EF%BC%88107rpm-p-126.html |
| 37 mm L braket | 46 × 42 × 40, sac 1,5, delik Ø3,5. Satıcıların çoğu ortalı milli GA37 braketi satıyor; JGB37'nin kaçık mili ve Ø31 delik düzeni kontrol edilmeli | orta | Amazon listeleri (arama özeti) |
| 125×58 tekerlek | Ø125 × 58, 12 mm altıgen göbek, 140 g | doğrulandı | https://www.robotistan.com/buyuk-arazi-tekerlegi-125mm-x-58mm · https://www.indianhobbycenter.com/products/125mm-atv-robotics-wheel-with-coupler-all-terrain-robot-monster-off-road-wheel-blue |
| Kaplin | 12 altıgen × 30, Ø6 delik, pirinç, 35 g (Robotistan kaplinsiz gönderiyor) | boy/delik doğrulandı | https://www.indianhobbycenter.com/products/30mm-long-hex-coupling-for-robot-smart-car-atv-wheel-6mm-shaft |
| DS3218MG | 40 × 20 × 40,4; kulaklarla 54,5; delik 49,5 × 10; kulak alt yüzü tabandan 27,7; mil kenardan ~10 (tahmini); 25T | doğrulandı | https://itgresa.com/wp-content/uploads/2025/10/DS-Servo-20kg-DS3218-PRO-datasheet-PDF.pdf |
| MG996R | 40,7 × 19,7 × 42,9 (kasa üstü 36,6, horn dahil 47,6); kulaklarla 53,6; kulak alt yüzü 26,6; 25T | doğrulandı | https://www.electronicoscaldas.com/datasheet/MG996R_Tower-Pro.pdf |
| Raspberry Pi 5 | 85 × 56; delik Ø2,7, 58 × 49, kenardan 3,5; bileşenler ~16 (tahmini) · Active Cooler 63,5 × 42,5 × 13,7 | doğrulandı | https://pip-assets.raspberrypi.com/categories/892-raspberry-pi-5/documents/RP-008347-DS-1-raspberry-pi-5-mechanical-drawing.pdf · https://www.olimex.com/Products/RaspberryPi/RPi5-ACOOL/resources/raspberry-pi-active-cooler-mechanical-drawing.pdf |
| Camera Module 3 | 25 × 23,86 × 1,12; delik Ø2,2, 21 × 12,5; lens Ø5,75, blok 10,8, lens merkezi alt kenardan 14,4; toplam 11,3 | doğrulandı | https://pip-assets.raspberrypi.com/categories/1207-design-files/documents/RP-008153-DS-1-camera-module-3-standard-mechanical-drawing.pdf |
| Waveshare 7" HDMI LCD | Kulaklarla 164,9 × 124,25; PCB 148,9 × 107,02; delik 156,9 × 114,96; aktif alan 154,21 × 85,92; panel 3,5, modül ~15 | doğrulandı (kalınlık tahmini) | https://www.waveshare.com/img/devkit/LCD/7AP/Exterior-Size.jpg · https://www.waveshare.com/wiki/7inch_HDMI_LCD_(C) |
| ESP32 DevKit | DevKitC V4 54,3 × 27,94 · DOIT 30 pin ~52 × 28 | doğrulandı / orta | https://dl.espressif.com/dl/schematics/esp32_devkitc_v4_dimensions.pdf |
| BTS7960 | 50 × 50 × 43, 4× M3 (aralık tahmini) | satıcı | https://envistiamall.com/blogs/learn/bts7960-double-43a-high-power-motor-driver-module-user-guide |
| PCA9685 | 62,2 × 25,4 × 3; delik Ø2,5, 55,9 × 19,05 | doğrulandı | https://www.adafruit.com/product/815 |
| LiFePO4 12,8V 20Ah | Landport LFP12-20 181 × 77 × 167, 2,8 kg · BATE 181 × 77 × 170, 2,9 kg · WattCycle 185 × 84 × 170, 2,05 kg | doğrulandı | https://www.oro2u.com/battery-lithium-12v-lfp12-20-20ah-12v-lithium-lifepo4-2-8kg-l-181-x-w-77-x-h-167 · https://batteryservice.cz/wp-content/uploads/2024/02/DataSheet-12.8V-20Ah-Lifepo4-Battery.pdf · https://www.wattcycle.com/products/wattcycle-12v-20ah-lifepo4-battery |
| 40×40 ağır sigma | Kanal 10,2; merkez Ø9; köşe delik Ø5,1 @ 30,2; 1,99 kg/m; kesit 7,32 cm² · köşe bağlantı 37 × 37 × 37,7, 75 g | doğrulandı | https://witcdn.robolinkmarket.com/40x40-agir-sigma-profil-kanal-10-1-metre-robolink-market-10848-77-B.jpg · https://sigmaprofil.com.tr/urun-detay/40x40-agir-sigma-profil-303 · https://witcdn.robolinkmarket.com/40x40-genis-kose-baglanti-robolink-market-2067-66-B.jpg |
| Emas B200E60 | Mantar Ø60; panel önü 28; arkası 48; delik Ø22,4; arka gövde 42 × 30 | doğrulandı | https://www.emaselectric.com/Export/File?fileUrl=%2FImages%2Fmedia%2FProduct%2FB200E60.jpg |
| HC-SR04 | 45 × 20 × 15; transdüser Ø16 | doğrulandı / tahmini | https://cdn.sparkfun.com/datasheets/Sensors/Proximity/HCSR04.pdf |
| XL4016 | Tek soğutuculu 65 × 47 × 23,5; delik 58 × 26 | orta | https://www.mikrocontroller.net/attachment/534859/XL4016_Step_Down_Buck_DC_DC_Converter.pdf |
| BNO055 (Adafruit) | 27 × 20 × 4; delik 20 × 12 | doğrulandı | https://www.adafruit.com/product/2472 |
| MAX98357A / hoparlör | 19,4 × 17,8 × 3 / Ø40 × 20, 27 g | doğrulandı | https://www.adafruit.com/product/3006 · https://www.adafruit.com/product/3968 |
| 50 mm sarhoş teker (Emes) | Toplam yükseklik 74; tabla 50 × 50; delik 38 × 38 | doğrulandı | https://www.tekerteker.com/emes-tablali-pvc-doner-tekerlek-50-mm-cap |

**Oran uyarısı (ajan):** 60 dev/dk hangi orana denk gelir, motorun boştaki devrine bağlı. ~6000 rpm motorda 1:90–100 (redüktör 24 mm), ~10000 rpm motorda 1:168 (26,5 mm). Modelde 24 mm kullanıldı.

## V2 ekranları (2 Ekim 2026, hoca geri bildirimi)

Kaynak: Claude Opus alt ajanı Waveshare çizimlerinden okudu; orkestratör fiyat ve stoğu sayfa verisinden yeniden kontrol etti.

| Parça | Ölçü (mm) | Durum | Kaynak |
|---|---|---|---|
| Waveshare 10.1inch HDMI LCD (B), kasalı | Kasa ön plakası 274,12 × 187,00 (R6); ön cam 253,96 × 168,60; cam penceresi 217,96 × 136,60; panel aktif alanı 216,96 × 135,60; çıplak panel 229,46 × 149,20 × 4,8; camdan arka plakaya 18,0; köşe delikleri Ø3,0, 265,11 × 179,0. CAD'de kasa ön plakası kullanılmadı, çerçeveyi gövde yapıyor (cam + 0,5 boşluk + 2,5 duvar). Kütle doğrulanmadı (CAD'de 0,60 kg tahmini) | doğrulandı (kütle tahmini) | https://files.waveshare.com/wiki/10.1inch_HDMI_LCD_B_with_case/10.1inch_HDMI_LCD_B_with_case_2D_PDF_20260116.pdf · https://files.waveshare.com/upload/9/9b/10.1inch_HDMI_LCD_B_panel_dimension.pdf |
| Waveshare 1.28inch LCD Module (GC9A01) | PCB Ø37,5, dil dahil 40,4; aktif Ø32,4; konnektörle 11,05, konnektörsüz ≈ 5,45; 4 pirinç burç Ø3,5 / Ø1,7, 18,6 × 26,7; PH2.0 8 pin. Kütle doğrulanmadı (CAD'de 8 g tahmini) | doğrulandı (kütle tahmini) | https://www.waveshare.com/wiki/1.28inch_LCD_Module · https://files.waveshare.com/upload/4/49/1.28inch_LCD_Module_3D_Drawing.zip |

## Kabuk modülü (8 Ekim 2026): 3D yazıcı ve göğüs ekranı

Kaynak: Claude Opus, FreeCAD kabuk modülü oturumu. Yazıcı değerleri üreticinin teknik sayfasından okundu; Nextion ölçüleri `donanim/datasheet/` altındaki çizimden. Bu değerler `tasarim/freecad/arayuz.py` içindeki `YAZICI` ve `NEXTION` sözlüklerine işlendi.

| Parça | Ölçü (mm) | Durum | Kaynak |
|---|---|---|---|
| Bambu Lab X2D (ekibin yazıcısı) | Baskı hacmi ana nozül 256 × 256 × 260; yardımcı nozül ve çift nozül 235,5 × 256 × 256; iki nozül toplam 256 × 256 × 260 · iki nozül (ana + yardımcı) · aktif ısıtmalı hazne en çok 65 °C · nozül 300 °C, tabla 120 °C · PLA, PETG, ABS, ASA, TPU, PA, PC, PET, PVA ve "Support for PLA/PETG" destek malzemesi. Kabukta kullanılabilir hacim her eksende 10 mm pay ile 246 × 246 × 250 (pay tahmini). Eski 250³ / PRINT_MAX 230 varsayımı geçersiz | doğrulandı (pay tahmini) | https://bambulab.com/en/x2d/specs |
| Nextion NX1060P101_011 (10,1", Intelligent) | PCB 258,00 × 152,00 × 1,60; cam (LCD + dokunmatik) 236,80 × 144,80; toplam kalınlık 9,80 ± 0,2 (sayfada bileşenlerle 11,5); aktif alan 222,72 × 125,28; görünen alan 235 × 143; delikler 4× Ø3,20, 251,60 × 145,60 (kenardan 3,2); cam PCB uzun kenarından 10,40, kısa kenarından 3,80; 535 g. 4 pin XH2.54 konnektörün yeri (alt kenardan 7,81, soldan 68,44, 15,12 genişlik) ve arka bileşen yüksekliği (6,00) çizimden yorum | doğrulandı (konnektör yeri tahmini) | `donanim/datasheet/NX1060P101-011C-I_dimension.pdf` · https://nextion.tech/datasheets/nx1060p101-011c-i/ |
| M3 ISO 7380 bombe başlı imbus | Baş Ø5,7 × 1,65, anahtar 2 (bindirme cıvataları) | standart (nominal) | ISO 7380-1 |

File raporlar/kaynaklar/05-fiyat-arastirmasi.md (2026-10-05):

---
title: "Kanıt: Parça fiyat araştırması ve doğrulama"
created: 2026-09-27
---

> Dört Claude Opus alt ajanının raporu (27 Eylül 2026) ve orkestratörün (Echo) doğrulama kaydı. Temiz liste
> `planlama/maliyet.json` dosyasında; sayfa `tasarim/Robot-Tasarim-Demosu.html` içindeki "Proje maliyeti" bölümü.
> Ajan raporları aşağıda kısaltılmadan (yalnız biçim düzeltilerek) duruyor; rakamlar ajanların beyanıdır, doğrulama
> sonucu ilk bölümde.

## 1. Kapsam

Malzeme listesi CAD montajındaki parçalardan (`tasarim/cad/parca-listesi.csv`, 4 motorlu önerilen yapı) ve
CAD'de çizilmeyen zorunlu kalemlerden (hafıza kartı, mikrofon, şarj cihazı, sigorta, kablo, klemens, filament,
vida) oluşuyor. Dört ajan paralel çalıştı: tahrik ve şase, işlemci ve sensörler, servo ve güç, üretim ve sarf
malzemesi ile kur. Üç ajan kullanım sınırı yüzünden bir kez kesildi ve kaldığı yerden sürdürüldü.

Kur: **1 USD = 48,8780 TL**, TCMB 25.09.2026 döviz satış (bülten 2026/181). Orkestratör XML'den ayrıca okudu:
https://www.tcmb.gov.tr/kurlar/202609/25092026.xml (27.09 Pazar olduğundan son iş günü). Serbest piyasa Cuma
kapanışı 48,9496 (fark ≈ %0,15).

## 2. Doğrulama (orkestratör, 27.09.2026)

**Yöntem.** Seçilen ve ikinci satıcı olarak gösterilen 75 ürün sayfası bir betikle yeniden açıldı. Fiyat ve stok,
sayfanın kendi yapısal verisinden (schema.org JSON-LD `offers.price` / `availability`, meta etiketleri) ve
görünür metinden okundu. Direnc, Motorobit, Robotsepeti, Robiz ve UserPil JSON-LD'de KDV hariç fiyat veriyor;
bunlar ×1,20 ile karşılaştırıldı. Ajanların beyanı değil, sayfanın o anki verisi esas alındı.

| Sonuç | Sayfa | Ayrıntı |
|---|---|---|
| Fiyat birebir tuttu | 71 / 75 | Kuruşu kuruşuna (Adafruit 29,25 USD ve Limacell 4.713,43 TL meta etiketinden) |
| Fiyat farklı | 1 | Hepsiburada ana sigorta yuvası: liste 550,00 TL; ajanın 495 TL'si sepete özel indirim. Listeye 550 TL yazıldı |
| Fiyat bulunamadı | 1 | Motorobit 30 A bıçak sigorta: arama sayfasında ad var, fiyat okunamadı → "tahmini" (4,20 TL, ajan beyanı) |
| Erişim engellendi | 2 | Trendyol WAGO sayfaları 403 → "tahmini" (ajanın tarayıcıdan okuduğu fiyat) |

**Yakalanan stok hataları.** Ajan 3 üç Direnc.net ürününe "stokta" demişti; sayfa verisi `OutOfStock` ve ürün
yorumlarında "stok ne zaman gelir?" soruları var:

| Kalem | Ajanın seçimi | Durum | Yerine (doğrulandı, stokta) |
|---|---|---|---|
| BTS7960B motor sürücü | Direnc.net 232,47 TL | Tükendi | Makermarketim 277,85 TL |
| XT60 konnektör çifti | Direnc.net 21,50 TL | Tükendi | Robotsepeti erkek 21,01 + dişi 21,61 = 42,62 TL |
| Makaron seti 750 parça | Direnc.net 232,47 TL | Tükendi | Robolink 328 parça kutulu 229,50 TL |

Beklendiği gibi tükenmiş olanlar: Camera Module 3 (Robotistan ve 5 satıcı daha), Orbus 20 Ah akü. Robotistan'da Pi 5
8 GB ve 7" LCD (C) sayfa verisine göre stokta (WebFetch özetinin "Tükendi" demesi şablondaki gizli bloktan).

**Orkestratörün diğer kararları.**
- WAGO 221-415 çıkarıldı (Trendyol'da tek adet stok); 221-413 10'lu paket yeterli. Star Akım 50'li paketle
  satıyor (1.003,50 TL), bu proje için fazla.
- Aküde Limacell 24 Ah seçildi: stoklu ve ölçüsü tutan 20 Ah bulunamadı; ölçü satıcıya sorulacak.
- Kargo: sepeti ücretsiz kargo eşiğini geçmeyen 7 sipariş × 120 TL (tahmini). Robolink'e makaron eklenince
  sepet 1.660,50 TL'ye çıkıp eşiği geçiyor.
- Beklenmeyen gider payı %15 (önceki fizibilitede %25'ti). Gerekçe: fiyatların çoğu artık doğrulandı, kargo ve
  yedek parça ayrı satırda. Sayfadan %0–25 arası seçilebiliyor.
- İkinci satıcı olarak yalnız betikle doğrulanan sayfalar gösterildi.

## 3. Sonuç (planlama/maliyet.json)

| Grup | TL | USD |
|---|---:|---:|
| İşlemci ve elektronik | 16.000,64 | 327,36 |
| Güç ve güvenlik | 10.717,89 | 219,28 |
| Ses ve görüntü | 8.229,97 | 168,38 |
| Tahrik ve şase | 7.900,94 | 161,65 |
| Üretim ve sarf (bölümün yazıcısıyla) | 5.487,53 | 112,27 |
| Servolar ve kol | 5.288,88 | 108,21 |
| Yedek parçalar | 1.632,81 | 33,41 |
| Kargo (tahmini) | 840,00 | 17,19 |
| **Parçalar ve kargo** | **56.098,66** | **1.147,73** |
| %15 beklenmeyen pay | 8.414,80 | 172,16 |
| **Genel toplam** | **64.513,46** | **1.319,89** |

Seçenekler: baskı hizmetiyle 68.831,71 TL; yedek parçasız 62.635,73 TL. 54 kalemin 48'i satıcı sayfasından
doğrulandı; 6'sı tahmini (lazer kesim ×2, M5 × 40 burç, 30 A sigorta, WAGO, kargo).

Önceki fizibilite tahmini (26.09, Orta/Pi 5): ≈ 61.700 TL (%25 pay dahil). Fark küçük; ama liste artık CAD
tasarımının gerçek parçalarına ve doğrulanmış satıcı sayfalarına dayanıyor.

---

# Ek: ajan raporları

## Ajan 1: tahrik ve şase

Fiyatlar ürün sayfalarından okundu. Stok bilgisi sayfadaki yapısal veriden (JSON-LD `availability`, Robotistan/Robolink'te `available/quantity`); Robotistan ve Robolink'te "Sepete Ekle" ve "Tükendi" düğmeleri şablonda birlikte durduğu için WebFetch özeti stoktaki ürüne yanlışlıkla "Tükendi" diyebiliyor. Motorobit, Robotsepeti ve Robiz'de JSON-LD fiyatı KDV hariç; KDV dahil fiyat sayfa metninden okundu. Trendyol, Hepsiburada, n11, Akakçe, Çiçeksepeti 403 verdi (Trendyol ve Hepsiburada'ya tarayıcıdan kısa bakıldı; M5×40 distans ve JGB37 enkoderli motor için uygun ürün çıkmadı).

### 1. Ham bulgular

| # | Kalem | Satıcı | Sayfadaki ürün adı | Birim TL (KDV dahil) | Stok | URL | Not |
|---|---|---|---|---|---|---|---|
| 1 | Motor | Direnc.net | JGB37-520 - 12V 60RPM Enkoderli Motor | 639,29 | Stokta | https://www.direnc.net/jgb37-520-12v-60rpm-enkoderli-motor | 12V, 60 rpm, enkoderli, 21 kg. Mil/D, Hall ve oran sayfada yazmıyor. Önceki fiyatla aynı |
| 1 | Motor | Robotistan | JGB37 520 12V 1000RPM Encoderli DC Motor | 622,12 | Tükendi | https://www.robotistan.com/jgb37-520-12v-1000rpm-encoderli-dc-motor | Yanlış RPM, elendi |
| 1 | Motor | Robotistan | 12V 37mm 66 RPM Redüktörlü DC Motor (JGB37-520) | 401,26 | Tükendi | https://www.robotistan.com/12v-35mm-66-rpm-dc-gear-motor | Enkodersiz, elendi |
| 1 | Motor | Robotsepeti | 12V 60Rpm 37mm Redüktörlü DC Motor | 940,53 | Stokta yok | https://www.robotsepeti.com/12v-60rpm-37mm-reduktorlu-dc-motor | Enkodersiz, elendi |
| 1 | Motor | Amazon.com (t) | JGB37-520 Hall Encoder 12V 60Rpm | — | Currently unavailable | https://www.amazon.com/dp/B08KXQ2PZH | İthal seçenek de yok |
| 2 | Braket | Robotistan | Aluminyum L tipi 37D Motor Tutucu (İkili) PL-1084 | 746,55 / çift | Stokta (17) | https://www.robotistan.com/aluminyum-l-tipi-37d-motor-tutucu | Pololu 37D (kaçık mil) için; JGB37 uyumu yazmıyor |
| 2 | Braket | Robotzade | 37 mm Motor Tutucu Aparat Metal | 111,72 | Stokta | https://www.robotzade.com/urun/37-mm-motor-tutucu-aparat-metal | Tekli, 6 M3 vida dahil. L tipi mi, kaçık mile uyar mı belirtilmemiş |
| 2 | Braket | Robotus (Jsumo) | 37 mm Motor Bağlantı Aparatı (2 Adet) | 262,76 / çift | Stokta | https://www.robotus.net/37-mm-motor-baglanti-aparati-2-adet | 2 mm paslanmaz, 6 delik 60° |
| 2 | Braket | Motorobit | 37 mm Motor Tutucu | 105,00 | Tükendi | https://www.motorobit.com/37-mm-motor-tutucu | |
| 3 | Kaplin | Motorobit | 6mm Motor Şaftı ile Uyumlu Hex Tekerlek Kaplini | 120,00 | Stokta (100+) | https://www.motorobit.com/6mm-motor-safti-ile-uyumlu-hex-tekerlek-kaplini | Pirinç, 6 mm delik, ≈12 mm hex, 30 mm. Spec tam uyuyor |
| 3 | Kaplin | Robotsepeti | Hex Tekerlek Kaplini (6mm Motor Mili için) | 151,89 | Stokta | https://www.robotsepeti.com/hex-tekerlek-kaplini-6mm-motor-mili-icin | Aynı spec |
| 3 | Kaplin | Robotistan | Robot Araba Tekerlek Altıgen Kaplin 6mm 30mm | 77,99 | Tükendi | https://www.robotistan.com/robot-araba-tekerlek-altigen-kaplin-6mm-30mm | |
| 3 | Kaplin | Robotistan | Büyük Arazi Tekerleği İçin Metal Kaplin | 63,70 | Tükendi | https://www.robotistan.com/buyuk-arazi-tekerlegi-icin-metal-kaplin | 4 mm mil, elendi |
| 4 | Tekerlek | Robotistan | Büyük Arazi Tekerleği 125 mm x 58 mm - Mavi | 353,63 | Stokta (83) | https://www.robotistan.com/buyuk-arazi-tekerlegi-125mm-x-58mm-mavi | Kaplinsiz; göbek tipi yazmıyor |
| 4 | Tekerlek | Motorobit | Büyük Arazi Tekerleği 125mm x 58mm - Mavi | 600,00 | Stokta (10+) | https://www.motorobit.com/buyuk-arazi-tekerlegi-125mm-x-58mm-mavi | "6mm şafta uyumlu kapliniyle gönderilir" |
| 4 | Tekerlek | Robotsepeti | Jsumo Büyük Boy Arazi Tekerleği - 125mm | 588,33 | Stokta | https://www.robotsepeti.com/jsumo-buyuk-boy-arazi-tekerlegi-125mm-1-adet | Genişlik/göbek bilgisi yok |
| 5 | Sigma | CNC Marketi | 40X40 Sigma Profil 10 Kanal Ağır Tip | 908,32 / m | Stokta | https://www.cnc-marketi.com/urun/40x40-sigma-profil-10-kanal-agir-tip | 1,65 kg/m; en az 1 m, ara ölçü alınabiliyor, ölçüye kesim ücretsiz |
| 5 | Sigma | Otomasyoncu.net | Sigma Profil AĞIR 40x40 - Kanal 10 | 1.071,25 / m | Belirsiz | https://www.otomasyoncu.net/urun/sigma-profil-40x40-agir-kanal-10 | Kesim ücretsiz |
| 5 | Sigma | Robolink | 40x40 Ağır Sigma Profil-Kanal 10 - 1 Metre | 957,00 | Tükendi | https://www.robolinkmarket.com/40x40-agir-sigma-profil-kanal-10-1-metre | 834 TL referansı artık geçersiz |
| 5 | Sigma | Robolink | … - 500mm | 579,00 / parça | Stokta (5) | https://www.robolinkmarket.com/40x40-agir-sigma-profil-kanal-10-500mm | |
| 6 | Köşe | CNC Marketi | Geniş Köşe Bağlantı 40X40 K10 | 24,68 | Stokta | https://www.cnc-marketi.com/urun/genis-kose-baglanti-40x40-k10 | |
| 6 | Köşe | Robolink | 40x40 Geniş Köşe Bağlantı (Doğuş) | 39,00 | Stokta (10) | https://www.robolinkmarket.com/40x40-genis-kose-baglanti | |
| 6 | Köşe | Otomasyoncu.net | 40x40 Köşe Bağlantı GENİŞ | 30,61 | Belirsiz | https://www.otomasyoncu.net/urun/40x40-kose-baglanti-genis | |
| 7 | T-somun | CNC Marketi | 10 Kanal Profil Tırtıllı Somunu M6 | 3,78 | Stokta | https://www.cnc-marketi.com/urun/10-kanal-profil-tirtilli-somunu-m6 | |
| 7 | T-somun | CNC Marketi | T Kanal Somunu M6 / M5 45X45 K10 | 7,54 / 7,56 | Stokta | https://www.cnc-marketi.com/urun/t-kanal-somunu-m6-45x45-k10 | "45x45 K10" etiketli |
| 7 | T-somun | Otomasyoncu.net | Tırtıllı Somun Kanal 10 (M6 / M5) | 4,70 / 5,29 | Belirsiz | https://www.otomasyoncu.net/urun/tirtilli-somun-kanal-10 | |
| 7 | T-somun | Robolink | M5/40 Tırtıllı Kanal Somun | 10,50 | Stokta (2) | https://www.robolinkmarket.com/m5-40-tirtilli-kanal-somun | Kanal 8, elendi |
| 7 | Civata | CNC Marketi | M6X16 Fosfat Allen İmbus Civata | 3,50 | Stokta | https://www.cnc-marketi.com/urun/m6x16-fosfat-allen-alyan-basli-imbus-civata | |
| 8 | Distans | — | M5×40 dişi-dişi | bulunamadı | — | — | Robotistan, Motorobit, Robotsepeti, Direnc, Robolink, Hatfon, Trendyol'da yok |
| 8 | (referans) | Motorobit | M3 40mm Metal Dişi-Dişi Aralayıcı | 14,40 | Stokta | https://www.motorobit.com/m3-40mm-metal-female-female-spacer-standoff-metal-distance | Yalnız tahmin dayanağı |
| 9 | Servo braket | Robiz | Servo Bracket Montaj Parçası (MG995/MG996R) | 88,20 | Stok Var | https://robiz.net/servobracket | 2,2 mm Al |
| 9 | Servo braket | Robotistan | Çok Fonksiyonlu Servo Motor Tutucu | 63,70 | Tükendi | https://www.robotistan.com/cok-fonksiyonlu-servo-motor-tutucu | |
| 9 | Servo braket | Pazarama (Alkatronik) | Servo Motor Metal Montaj Parçası Braket | 180,83 | Stokta | https://www.pazarama.com/servo-motor-metal-montaj-parcasi-braket-mg995-mg996r-s3003-td-8120mg-aluminyum-tutucu-p-ALK01001329 | |
| 10 | Uzun U | Robiz | Uzun U Servo Bracket | 88,20 | Stok Var | https://robiz.net/longubracket | 2 mm Al |
| 10 | Uzun U | Pazarama (Alkatronik) | Uzun U Servo Motor Metal Montaj Parçası Braket | 149,09 | Stokta | https://www.pazarama.com/uzun-u-servo-motor-metal-montaj-parcasi-braket-mg995-mg996r-s3003-td-8120mg-aluminyum-tutucu-p-ALK01001596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 | |

### 2. Önerilen seçim (ajanın)

| # | Kalem | Satıcı | Birim TL | Adet | Toplam TL | Durum |
|---|---|---|---|---|---|---|
| 1 | JGB37-520 60rpm enkoderli | Direnc.net | 639,29 | 4 | 2.557,16 | doğrulandı |
| 2 | 37 mm motor braketi | Robotzade | 111,72 | 4 | 446,88 | fiyat doğrulandı; JGB37 uyumu teyitsiz |
| 3 | Hex kaplin 6→12 mm | Motorobit | 120,00 | 4 | 480,00 | doğrulandı |
| 4 | Arazi tekerleği 125×58 | Robotistan (mavi) | 353,63 | 4 | 1.414,52 | doğrulandı |
| 5 | 40×40 ağır sigma K10 | CNC Marketi | 908,32/m | 2,70 m | 2.452,46 | doğrulandı (kesim ücretsiz) |
| 6 | Geniş köşe bağlantı K10 | CNC Marketi | 24,68 | 4 | 98,72 | doğrulandı |
| 7 | T-somun M6 K10 + M6x16 civata | CNC Marketi | 3,78 + 3,50 | 40 + 40 | 291,20 | doğrulandı |
| 8 | M5×40 dişi-dişi distans | — | ~40 | 4 | ~160 | tahmini |
| 9 | Çok amaçlı servo braketi | Robiz | 88,20 | 2 | 176,40 | doğrulandı |
| 10 | Uzun U servo braketi | Robiz | 88,20 | 1 | 88,20 | doğrulandı |
| | **Toplam** | | | | **≈8.165** | kargo hariç |

Gerekçeler: Motor için stokta ve spec'e uyan tek TR satıcı Direnc. Kaçık mile resmi uyan Pololu PL-1084 (1.493,10 TL, 3,3 kat pahalı). Robotistan tekerlek + Motorobit kaplin = 1.894,52 TL; Motorobit kaplinli tekerlek 4 adet 2.400 TL. Sigma kesim listesi 2×500, 3×260, 1×700, 1×200; 2,70 m (≈20 mm testere payı). Tam 3 m = 2.724,96 TL.

### 3. Kargo
Direnc 1.500 TL (2.557 → ücretsiz). Robotistan 1.500 TL (1.414,52 → ücretli; 5. yedek tekerlekle ücretsiz). Motorobit 2.500 TL (480 → ücretli). CNC Marketi 132 TL, 2.400 TL üzeri ücretsiz (2.842,38 → ücretsiz). Robiz 1.100 TL Sürat / 1.500 TL Yurtiçi (264,60 → ücretli). Robotzade eşik görülmedi.

### 4. Açık kalanlar
- M5×40 dişi-dişi distans TR'de bulunamadı (~40 TL/adet tahmin). Alternatifler: M5 uzatma somunu, M5 saplama + 40 mm boru, baskılı burç + uzun M5 civata.
- JGB37: Direnc sayfası 6 mm D mil, Hall enkoder ve 1:90 oranını yazmıyor; datasheet'ten teyit. TR'de ikinci stoklu satıcı yok.
- Tekerlek göbeği: Robotistan 12 mm hex'i açıkça yazmıyor; Motorobit 6 mm kaplin dahil gönderiyor.
- Motor braketi kaçık mil uyumu doğrulanmadı.
- T-somun tipi montaj sırasına göre kontrol edilmeli.
- Robolink sigma 834 → 957 TL, 1 m ürün tükendi.

## Ajan 2: işlemci, sensörler, ses ve görüntü

**Yöntem:** Fiyat ve stok ürün sayfalarının HTML'inden okundu: JSON-LD ve T-Soft `PRODUCT_DATA` alanları (`total_sale_price` KDV dahil, `available`, `quantity`); SAMM Market'te JSON-LD ve `stockCount`.

**Dikkat:** WebFetch özetleri Robotistan'da gizli duran "Tükendi" bloğunu okuyup yanlış sonuç veriyor. Pi 5 8GB ve LCD (C) sayfalarında sayfa verisi "stokta" (116 ve 99 adet), WebFetch "Tükendi" dedi. Robotistan, Direnc, Robotsepeti ve Motorobit'te fiyatların temel para birimi USD, sayfada TL gösteriliyor; fiyatlar günlük değişebilir.

### 1. Ham bulgular

| # | Kalem | Satıcı | Sayfadaki ürün adı | Birim TL (KDV dahil) | Stok | URL | Not |
|---|---|---|---|---|---|---|---|
| 1 | Pi 5 8GB | Robotistan | Raspberry Pi 5 8GB | 11.966,22 | Stokta (116) | https://www.robotistan.com/raspberry-pi-5-8-gb | 26.09'da tükenmişti. Satış 1 adetle sınırlı |
| 1 | Pi 5 8GB | SAMM | Raspberry Pi 5 - 8 GB | 12.057,68 | Stokta (122) | https://market.samm.com/raspberry-pi-5 | Resmi TR distribütörü |
| 1 | Pi 5 8GB | Direnc | Raspberry Pi 5 - 8GB | 12.204,69 | Stokta (3) | https://www.direnc.net/raspberry-pi-5-8gb | |
| 1 | Pi 5 8GB | Motorobit | Raspberry Pi 5 - 8GB | 13.320,00 | Tükendi | https://www.motorobit.com/raspberry-pi-5-8gb | |
| 1 | Pi 5 8GB | Robotsepeti | Raspberry Pi 5 - 8Gb | 16.329,24 | Stokta | https://www.robotsepeti.com/raspberry-pi-5-8gb | |
| 1 | Pi 5 8GB | Robolink | Raspberry Pi 5 - 8GB | 6.745,50 | Tükendi | https://www.robolinkmarket.com/raspberry-pi-5-8gb | Eski fiyat olabilir |
| 2 | Soğutucu | SAMM | Raspberry Pi 5 Aktif Soğutucu | 308,19 | Stokta (497) | https://market.samm.com/raspberry-pi-5-aktif-sogutucu | Resmi |
| 2 | Soğutucu | Robotistan | Raspberry Pi Active Cooler | 314,34 | Stokta (280) | https://www.robotistan.com/raspberry-pi-active-cooler-en | Resmi |
| 2 | Soğutucu | Robolink | Raspberry Pi 5 Aktif Soğutucu | 399,00 | Stokta (16) | https://www.robolinkmarket.com/raspberry-pi-5-aktif-sogutucu | |
| 2 | Soğutucu | Direnc | Raspberry Pi 5 Aktif Fanlı Soğutucu | 395,20 | Tükendi | https://www.direnc.net/raspberry-pi-5-aktif-fanli-sogutucu | Arama listesinden |
| 2 | Soğutucu | Robotsepeti | Raspberry Pi 5 Aktif Soğutucu Heatsink - 5V | 412,88 | Stokta (9) | https://www.robotsepeti.com/raspberry-pi-5-aktif-sogutucu-heatsink | Resmi olup olmadığı belirsiz |
| 3 | microSD | SAMM | Raspberry Pi 64GB A2 Class Hafıza Kartı | 2.166,16 | Stokta (313) | https://market.samm.com/raspberry-pi-64gb-a2-class-hafiza-karti | Resmi, A2 |
| 3 | microSD | Vatan | Sandisk Extreme Pro 64 GB (200MB/s) | 2.249,00 | Stokta | https://www.vatanbilgisayar.com/sandisk-extreme-pro-64-gb-hafiza-karti-200mb-s.html | microSDXC SDSQXCU-064G, A2 |
| 3 | microSD | SAMM | SanDisk Extreme Pro 64GB | 1.350,18 | Tükendi | https://market.samm.com/sdsqxcu-064g-gn6ma-sandisk-extreme-pro-64gb-200-90mb-s-microsdxc-uhs-i-a2-v30-hafiza-karti | |
| 3 | microSD | Direnc | Samsung EVO Plus 64GB 95 MB/s | 900,82 | Tükendi | https://www.direnc.net/samsung-evo-plus-64gb-95-mb/s-microsdhc-kart | A1, A2 değil |
| 4 | Kamera M3 | Robotistan | Raspberry Pi Camera Module 3 | 1.791,36 | Tükendi | https://www.robotistan.com/raspberrypi-camera-module | Standart |
| 4 | Kamera M3 | SAMM | Raspberry Pi Kamera Modül 3 | 2.246,77 | Tükendi (0) | https://market.samm.com/raspberry-pi-kamera-3 | |
| 4 | Kamera M3 | Robotizmo | Raspberry Pi Kamera Modül 3 | 2.255,49 | Tükendi | https://www.robotizmo.net/raspberry-pi-kamera-modul-3 | |
| 4 | Kamera M3 | Robolink | Raspberry Pi Kamera Modül 3 - Standart Lens | 2.817,00 | Tükendi | https://www.robolinkmarket.com/raspberry-pi-kamera-modul-3 | |
| 4 | Kamera M3 | Robotsepeti | Kamera Modülü 3 Standart SC1223 | 2.941,66 | Tükendi (0) | https://www.robotsepeti.com/raspberry-pi-kamera-kamera-modulu-3-imx708-12mp-autofocus-75-fov | Arama listesinden |
| 4 | Kamera M3 | Özdisan | RASPBERRY Pİ KAMERA V3 ORİJİNAL | fiyat yok | 0 | https://www.ozdisan.com/p/tek-kart-bilgisayar-modulleri-867/raspberry-raspberry-p-kamera-v3-1199863 | |
| 4 | Kamera M3 | Adafruit | Camera Module 3 Standard | 29,25 USD | InStock | https://www.adafruit.com/product/5657 | (t) ithal |
| 4 | (spec dışı) | Robotsepeti | Kamera Modülü 3 NOIR / Wide | 2.521,43 / 3.887,80 | Stokta | https://www.robotsepeti.com/raspberry-pi-kamera-modulu-3-noir | NoIR ve Wide istenmiyordu |
| 5 | FPC kablo | SAMM | Raspberry Pi 5 Kamera FPC Kablosu (200mm) | 70,44 | Stokta (147) | https://market.samm.com/raspberry-pi-5-kamera-fpc-kablosu | Resmi SC1128; 300 mm 140,89 |
| 5 | FPC kablo | Robolink | Raspberry Pi 5 Kamera FPC Kablosu - 200mm | 84,00 | Stokta (23) | https://www.robolinkmarket.com/raspberry-pi-5-kamera-fpc-kablosu-200mm | |
| 5 | FPC kablo | Robotsepeti | Raspberry Pi 5 Kamera için FPC Kablosu - 200mm | 91,25 | Stokta (43) | https://www.robotsepeti.com/raspberry-pi-5-kamera-icin-fpc-kablosu-200mm | |
| 6 | 7" LCD | Robotistan | WaveShare 7 Inch HDMI Kapasitif Dokunmatik LCD - 1024x600 (C) | 2.758,18 | Stokta (99) | https://www.robotistan.com/7-hdmi-kapasitif-dokunmatik-lcd-ekran-1024x600 | Paket: HDMI kablosu var, micro HDMI yazmıyor |
| 6 | 7" LCD | Robotistan | WaveShare 7 inch HDMI Rezistif Dokunmatik LCD | 2.903,45 | Stokta (49) | https://www.robotistan.com/7-inch-hdmi-rezistif-dokunmatik-lcd-1024x600 | 26.09 referansı; (C) değil |
| 6 | 7" LCD | Direnc | Raspberry 7 Inch HDMI Lcd C Ekran 1024×600 IPS | 2.931,97 | Stokta (8) | https://www.direnc.net/raspberry-7inch-hdmi-lcd-c-1024600-ips-supports-various-systems-waveshare | |
| 6 | 7" LCD | SAMM | Raspberry Pi 7 inç 1024x600 HDMI Kapasitif IPS LCD (C) | 3.052,58 | Stokta (51) | https://market.samm.com/raspberry-pi-7-hdmi-dokunmatik-ips-lcd-c-ekran | Paket: HDMI + HDMI→micro HDMI kablo |
| 6 | 7" LCD | Amazon.com.tr | WaveShare 7 Inch HDMI Kapasitif LCD (C) | 3.551,88 | Stokta | https://www.amazon.com.tr/dp/B09RMQSPPX | |
| 6 | 7" LCD | Robotsepeti | Waveshare 7inch HDMI LCD (C) | 4.082,31 | Stokta (10) | https://www.robotsepeti.com/waveshare-7inch-hdmi-lcd-c-ic-test-board | |
| 6 | 7" LCD | Motorobit | WaveShare 7 Inch (C) 1024x600 | 5.100,00 | Stokta (13) | https://www.motorobit.com/waveshare-7-inch-c-1024x600-dokunmatik-hdmi-ekra | |
| 7 | µHDMI kablo | Robotistan | HDMI Erkek Mikro HDMI Erkek Altın Uçlu Kablo - 1.5 M | 114,30 | Stokta (322) | https://www.robotistan.com/hdmi-erkek-mikro-hdmi-erkek-altin-uclu-kablo-1 | 1,5 m |
| 7 | µHDMI kablo | Robolink | HDMI - Micro HDMI Kablo 1.5M | 126,00 | Stokta (11) | https://www.robolinkmarket.com/hdmi-micro-hdmi-kablo-15m-al-4281 | |
| 7 | µHDMI kablo | SAMM | Orijinal Raspberry Pi Mikro Hdmi - Hdmi Kablo (SC0224) | 234,81 | Stokta (21) | https://market.samm.com/orijinal-raspberry-pi-mikro-hdmi-hdmi-kablo | ~235 mm, HDMI ucu dişi |
| 8 | ESP32 | Robolink | ESP32-WROOM-32D Wifi Bluetooth Geliştirme Modülü | 355,50 | Stokta (8) | https://www.robolinkmarket.com/esp32-wroom-32d-wifi-bluetooth-gelistirme-modulu | Pin sayısı sayfada yok |
| 8 | ESP32 | Direnc | ESP32-WROOM-32D Wifi Bluetooth Geliştirme Board | 377,76 | Stokta (1929) | https://www.direnc.net/esp32-wroom-32d-wifi-bluetooth-gelistirme-board | 26.09'da 275,22 TL |
| 8 | ESP32 | Robotistan | ESP32 ESP-32S WiFi+BT Geliştirme Kartı (30 Pin) | 416,14 | Stokta (1161) | https://www.robotistan.com/esp32-esp-32s-wifi-bluetooth-dual-mode-gelistirme-karti | 30 pin; ESP-WROOM-32 (32D değil) |
| 9 | PCA9685 | SAMM | PCA9685 16 Kanal I2C PWM/Servo Sürücü Kartı (Klon) | 197,15 | Stokta (7) | https://market.samm.com/pca9685-16-kanal-i2c-pwm-servo-surucu-karti-klon | |
| 9 | PCA9685 | Robotistan | PCA9685 16 Kanal I2C PWM/Servo Sürücü Kartı (Klon) | 241,71 | Stokta (52) | https://www.robotistan.com/pca9685-16-kanal-i2c-pwmservo-surucu-karti-klon | |
| 9 | PCA9685 | Robolink | PCA9685 16 Kanal 12-bit PWM Sürücü | 345,00 | Tükendi | https://www.robolinkmarket.com/pca9685-16-kanal-12-bit-pwm-surucu | 26.09 referansı |
| 9 | PCA9685 | Motorobit | 16 Kanal I2C PWM/Servo Sürücü Kartı PCA9685 | 390,00 | Stokta (16) | https://www.motorobit.com/16-kanal-i2c-pwmservo-surucu-karti-pca9685 | |
| 10 | BNO055 | Robotistan | BNO055 9DOF Sensör Modül | 753,10 | Stokta (5) | https://www.robotistan.com/bno055-9dof-sensor-modul | Muadil, 3,3/5 V regülatörlü |
| 10 | BNO055 | Robotistan | Boardoza BNO055 IMU Sensör Modülü | 1.146,02 | Stokta (6) | https://www.robotistan.com/boardoza-bno055-imu-sensor-modulu | |
| 10 | BNO055 | Robotsepeti | Adafruit BNO055 STEMMA QT | 2.974,68 | Stokta (8) | https://www.robotsepeti.com/adafruit-bno055-9-dof-mutlak-oryantasyon-imu-breakout-sensor | Orijinal Adafruit |
| 11 | HC-SR04 | Robolink | HC-SR04 Arduino Ultrasonic Mesafe Sensörü | 54,00 | Stokta (131) | https://www.robolinkmarket.com/hc-sr04-arduino-ultrasonic-mesafe-sensoru | |
| 11 | HC-SR04 | Direnc | HC-SR04 Arduino Ultrasonik Mesafe Sensörü | 58,12 | Stokta (1735) | https://www.direnc.net/arduino-ultrasonic-sensor-hc-sr04 | |
| 11 | HC-SR04 | Robotistan | HC-SR04 Ultrasonik Mesafe Sensörü | 62,51 | Stokta (26) | https://www.robotistan.com/hc-sr04-ultrasonik-mesafe-sensoru | |
| 12 | Mik. (bütçe) | Amazon.com.tr | Audio-Technica ATR4750 USB Tüm Yönlü Kuğu Boynu | 1.962,11 | Son 1 adet | https://www.amazon.com.tr/dp/B086CV7FWS | Omni; Linux UAC doğrulanmadı |
| 12 | Mik. (bütçe) | Amazon.com.tr | Boya BY-M100UA Kompakt USB Mikrofon | 1.199,90 | Stokta | https://www.amazon.com.tr/dp/B097HRS4TP | Yönlülük yazmıyor |
| 12 | Mik. (iyi) | Robotsepeti | ReSpeaker Lite 2 Mikrofon Uzak Alan AI Ses Kartı | 2.587,46 | Stokta (37) | https://www.robotsepeti.com/respeaker-lite-2-mikrofon-uzak-alan-ai-ses-tanima-ve-isleme-karti | XMOS XU316, USB/I2S, çıplak kart |
| 12 | Mik. (iyi) | Robotistan | ReSpeaker Mic Array v2.0 | 6.520,70 | Stokta (7) | https://www.robotistan.com/respeaker-mic-array-v20-eng | 4 mikrofon, XVF-3000 |
| 13 | MAX98357A | Amazon.com.tr | SANEC MAX98357 I2S 5V 3W Class-D | 227,23 | Stokta | https://www.amazon.com.tr/dp/B0HHTWJWYG | Muadil |
| 13 | MAX98357A | Robotsepeti | Adafruit MAX98357 3W Class D I2S | 728,81 | Stokta (50) | https://www.robotsepeti.com/adafruit-3w-class-d-amplifikator-breakout-karti-i2s | Orijinal Adafruit |
| 14 | Hoparlör | Motorobit | Speaker 4 ohm 3W 40mm | 105,00 | Stokta (1762) | https://www.motorobit.com/speaker-4-ohm-3w-40mm | |
| 14 | Hoparlör | Aletler.com.tr | 4 Ohm 3W Hoparlör 4cm | 68,99 | Belirsiz | https://www.aletler.com.tr/urun/4-ohm-3w-hoparlor-4cm | |
| 15 | Buton | Robotistan | 43mm LED Arcade Basmalı Buton Kırmızı | 74,42 | Stokta (80) | https://www.robotistan.com/43mm-led-arcade-basmali-buton-kirmizi | 43 mm, anlık |
| 15 | Buton | Direnc | 22mm Kırmızı Işıklı Yaylı Buton 1NO/1NC | 269,48 | Stokta (10) | https://www.direnc.net/22mm-kirmizi-yayli-buton-1no1nc | 22 mm panel tipi |

### 2. Önerilen seçim (ajanın)

| # | Kalem | Satıcı | Birim TL | Adet | Toplam TL | Stok | Durum |
|---|---|---|---|---|---|---|---|
| 1 | Pi 5 8GB | Robotistan | 11.966,22 | 1 | 11.966,22 | Stokta* | doğrulandı |
| 2 | Active Cooler | Robotistan | 314,34 | 1 | 314,34 | Stokta | doğrulandı |
| 3 | microSD 64GB A2 | SAMM | 2.166,16 | 1 | 2.166,16 | Stokta | doğrulandı |
| 4 | Camera Module 3 | Robotistan | 1.791,36 | 1 | 1.791,36 | **Tükendi** | fiyat doğrulandı, stok yok; yedek Adafruit 29,25 USD ithal |
| 5 | FPC kablo 200mm | SAMM | 70,44 | 1 | 70,44 | Stokta | doğrulandı |
| 6 | 7" HDMI LCD (C) | Robotistan | 2.758,18 | 1 | 2.758,18 | Stokta* | doğrulandı |
| 7 | µHDMI→HDMI | Robotistan | 114,30 | 1 | 114,30 | Stokta | doğrulandı (1,5 m) |
| 8 | ESP32 30 pin | Robotistan | 416,14 | 1 | 416,14 | Stokta | doğrulandı (WROOM-32) |
| 9 | PCA9685 | SAMM | 197,15 | 1 | 197,15 | Stokta (7) | doğrulandı |
| 10 | BNO055 | Robotistan | 753,10 | 1 | 753,10 | Stokta (5) | doğrulandı (muadil) |
| 11 | HC-SR04 | Robotistan | 62,51 | 3 | 187,53 | Stokta | doğrulandı |
| 12b | Mikrofon (öneri) | Robotsepeti ReSpeaker Lite | 2.587,46 | 1 | 2.587,46 | Stokta (37) | doğrulandı |
| 13 | MAX98357A | Robotsepeti (Adafruit) | 728,81 | 1 | 728,81 | Stokta | doğrulandı |
| 14 | Hoparlör | Motorobit | 105,00 | 1 | 105,00 | Stokta | doğrulandı |
| 15 | Bas-konuş butonu | Robotistan | 74,42 | 1 | 74,42 | Stokta | doğrulandı (43 mm) |
| | **Toplam** | | | | **24.230,61** | | kamera hariç 22.439,25 |

\* Robotistan stok bilgisi WebFetch özetiyle çelişiyor.

Gerekçeler: Robotistan tek sepette en ucuz/ucuza yakın; Pi 5 yedeği SAMM (12.057,68, resmi distribütör, 122 stok). Mikrofonda ReSpeaker Lite öneriliyor (XMOS DSP gürültü bastırma, UAC, bütçe mikrofondan ~625 TL pahalı); ATR4750'de DSP yok.

### 3. Kargo
Robotistan / Direnc / Robolink / SAMM / Vatan: 1.500 TL. Motorobit: 2.500 TL. Robotsepeti: 1.250 TL? (yalnız arama özetinden). Eşik altı ücret hiçbir sayfadan okunamadı.

### 4. Açık kalanlar
1. Camera Module 3 (standart) hiçbir TR satıcıda stokta değil (Robotistan, SAMM, Robolink, Robotsepeti, Robotizmo, Özdisan). Stok alarmı ya da Adafruit ithal.
2. Robotistan stok çelişkisi (Pi 5, LCD): sipariş öncesi tarayıcıdan bakılmalı.
3. ESP32: 30 pini açıkça yazan Robotistan kartı ESP-WROOM-32; kod ve pin düzeni aynı.
4. 1 m'den kısa µHDMI erkek-erkek kablo bulunamadı. SAMM LCD (C) paketinde HDMI→micro HDMI kablo var diyor; kutu içeriği doğrulanırsa 7. kalem gereksiz.
5. 30 mm arcade buton bulunamadı; 43 mm seçildi, uymazsa Direnc 22 mm (269,48).
6. BNO055 seçilen muadil; orijinal Adafruit 2.974,68 TL.
7. ReSpeaker Lite'ın USB (UAC) firmware'iyle gelip gelmediği Seeed wiki'den kontrol edilmeli.
8. Açılamayan siteler: Akakçe, Hepsiburada, Trendyol, n11, Teknosa, incehesap, Farnell TR, PiShop (403); Komponentci, Havyatech (DNS).
9. 26.09 referanslarındaki değişimler: Direnc ESP32 275,22 → 377,76; Robolink PCA9685 345 (tükendi); Robotistan 7" referansı (C) değil rezistif, 2.903,45 TL.

## Ajan 3: servolar, motor sürücüleri, güç ve güvenlik

Fiyatların hepsi ürün sayfasından okundu, KDV dahil; sayfada "+KDV" yazanlara %20 eklendi. Oturum sonunda WebSearch/WebFetch kullanım sınırına takıldı, kalan kontroller tarayıcıyla yapıldı.

### 1. Ham bulgular

| # | Kalem | Satıcı | Sayfadaki ürün adı | Birim TL | Stok | URL | Not |
|---|---|---|---|---|---|---|---|
| 1 | DS3218MG | Robocombo | DSSERVO DS3218 20kg Servo Motor - 180 Derece - Su | 959,40 | Stokta (225) | https://www.robocombo.com/dsservo-ds3218-20kg-servo-motor-180-derece-su--4151 | Teknik tabloda "Model: DS3218MG"; dişli malzemesi yazmıyor |
| 1 | DS3218MG | Motorobit | DS3218MG 20KG Waterproof Digital Servo Motor | 1.290,00 | Stokta (10+) | https://www.motorobit.com/ds3218mg-20kg-waterproof-digital-servo-motor | 180° |
| 1 | DS3218MG | Görsu | DS3218MG 20KG Su Geçirmez Dijital Servo Motor | 1.291,26 (1.076,05+KDV) | Stokta | https://gorsuelektronik.com/tr-urun-ds3218mg-20kg-su-gecirmez-dijital-servo-motor | Metal dişli |
| 1 | DS3218MG | Robotsepeti | DSServo DS3218MG 20kg … 180°, IP66 | 1.560,88 | Stokta | https://www.robotsepeti.com/dsservo-ds3218mg-20kg-su-gecirmez-dijital-servo-motor-180 | |
| 1 | DS3218MG | Robolink (ref.) | DS3218MG 20Kg Dijital Servo Motor | 1.594,50 | Tükendi | https://www.robolinkmarket.com/ds3218mg-20kg-dijital-servo-motor | |
| 2 | MG996R | Robocombo | Tower Pro MG996R Metal Dişli Dijital Servo Motor 180 Derece | 197,78 | Stokta (64, kritik) | https://www.robocombo.com/tower-pro-mg996r-metal-disli-dijital-servo-motor-180-derece | |
| 2 | MG996R | Motorobit | MG996R Servo Motor 180 Derece (Tower Pro) | 282,00 | Stokta (100+) | https://www.motorobit.com/mg996r-metal-disli-servo-motor | İçte plastik dişli var |
| 2 | MG996R | Robotsepeti | Tower Pro MG996R Servo Motor 180 Derece | 256,35 | Stokta | https://www.robotsepeti.com/tower-pro-mg996-r-servo-motor-180 | |
| 2 | MG996R muadil | Kartal Otomasyon | KO MG996R Servo Motor | 233,44 | Belirsiz | https://www.kartalotomasyon.com.tr/urun/mg996r-servo-motor | |
| 2 | MG996R | Robotistan (ref.) | MG996R Yüksek Torklu Servo Motor - 180 Derece | 230,99 | Tükendi | https://www.robotistan.com/mg996-13-kg-servo-motor | |
| 2 | MG996R | Robolink | MG996R Servo Motor | 291,00 | Tükendi | https://www.robolinkmarket.com/tower-pro-mg996r-servo-motor | "Klon" |
| 3 | BTS7960 | Direnc.net | BTS7960B 40 Amper Motor Sürücü Modülü | 232,47 | Stokta | https://www.direnc.net/bts7960b-40-amper-motor-surucu-modulu-1 | IBT-2 tipi; eski referans URL ana sayfaya gidiyor |
| 3 | BTS7960 | Makermarketim | BTS7960B 40 Amper Motor Sürücü Modülü | 277,85 | Stokta | https://www.makermarketim.net/bts7960b-40-amper-motor-surucu-modulu | |
| 3 | BTS7960 | Robotistan / Robolink / Robotsepeti / Motorobit | BTS7960B | 258,97 / 390,00 / 360,20 / 450,00 | Hepsi Tükendi | https://www.robotistan.com/bts7960b-40-amper-motor-driver-board | |
| 4 | XL4016 | Motorobit | XL4016 8A DC-DC Step Down (XH-M401) | 240,00 | Stokta (10+) | https://www.motorobit.com/xl4016-8a-dc-dc-step-down-voltage-regulator | Sürekli 5 A, 8 A'de fan şart |
| 4 | XL4016 | Robotronik | XL4016 8A DC-DC Step Down Potanslı | 170,10 | Stokta (22) | https://www.robotronik.com.tr/xl4016-8a-dc-dc-step-down-voltaj-regulatoru-potansli-a0188 | |
| 4 | XL4016 | Ulutaş | XL4016 LED 8A Dijital Voltaj Düşürücü | 275,68 | Stokta (90) | https://www.ulutaselektronik.com/urun/xl4016-led-8a-dc-dc-ayarlanabilir-dijital-voltaj-dusurucu-regulator-modulu | |
| 5 | Akü | Limacell (gecersunenerji) | Limacell Enerji 12 Volt 24 Ah Lifepo4 batarya | 4.713,43 | Sipariş üzerine üretim | https://www.gecersunenerji.com/12-volt-24-ah-lifepo4-batarya | 12,8 V, 30 A sürekli / 45 A anlık, 307 Wh; ölçü yok |
| 5 | Akü | Limacell (gecersunenerji) | Limacell Enerji 12 Volt 18 Ah Lifepo4 batarya | 4.271,55 | Sipariş üzerine | https://www.gecersunenerji.com/12-volt-18-ah-lifepo4-batarya | 230 Wh |
| 5 | Akü | Merter Elektronik | Orbus 12.8 Volt 20 Amper LifePO4 Akü LIT-12-20 | 6.038,46 | Tükendi | https://www.merterelektronik.com/orbus-12.8-volt-20-amper-lityum-lifepo4-aku-lit-12-20 | 181×77×175 mm, 3 kg, BMS |
| 5 | Akü | Enerjimar | Orbus 12 Volt 20 Amper Lityum İyon Akü | 4.704,00 | Stokta yok | https://enerjimar.com/orbus-12-volt-20-amperlityum-iyon-aku | "Li-ion" yazıyor |
| 5 | Akü | Trendyol (Pil Servisi) | 12V 18Ah LiFePO4 Batarya | 3.950,00 | Son 2 ürün | https://www.trendyol.com/pil-servisi/12v-18ah-lifepo4-batarya-p-1151302447 | BMS/ölçü yok |
| 5 | Akü (t) | ExpertPower | 12V 20Ah LiFePO4 EP1220 | 129,99 USD | Stokta yok | https://www.expertpower.us/products/ep1220-20ah | BMS 20 A |
| 6 | Şarj | UserPil | 14.4 Volt 6 Amper Lifepo4 Şarj Cihazı (4s) | 1.642,30 (1.368,58+KDV) | Stokta | https://userpilbatarya.com/urun/14-4-volt-6-amper-lifepo4-sarj-cihazi-4s/ | CC-CV |
| 6 | Şarj | Pil Yurdu | 14.6V(4S) 6A CcCv LiFePO4 Şarj Cihazı | 1.947,60 | Stokta yok | https://pilyurdu.com/14-6v4s-6a-cccv-lifepo4-sarj-cihazi-12v-6a/ | |
| 7 | Acil stop | Elektrix | EMAS Acil Stop Mantar 40mm Emergency Etiketli B200E-E | 231,66 + kargo | Stokta | https://www.elektrix.com/acil-stop-mantar-40mm-emergency-etiketli | 1NK, çevirmeli, 22 mm montaj |
| 7 | Acil stop | Kartal Otomasyon | B200E60 60mm Mantar Acil Stop Butonu NO | 267,70 | Belirsiz | https://www.kartalotomasyon.com.tr/B200E60-60mm-Mantar-Acil-Stop-Butonu-NO,PR-55175.html | Sayfa "NO" diyor |
| 7 | Acil stop | Akakçe (ref.) | 22mm mantar stop | — | — | https://www.akakce.com/kumanda-butonu/en-ucuz-22mm-mantar-stop-butonu-fiyati,817168446.html | Ürün artık yok |
| 8 | Sigorta kutusu | Motorobit | 6 Channel Auto Blade Fuse Box | 309,00 | Stokta (100+) | https://www.motorobit.com/6-channel-auto-blade-fuse-box | 5A, 10A, 2×15A, 2×20A sigorta dahil |
| 8 | 30A sigorta | Motorobit | 30 Amp Car Fuse - Blade Fuse | 4,20 | Belirsiz | https://www.motorobit.com/arama?q=b%C4%B1%C3%A7ak+sigorta | Yalnız arama listesi |
| 8 | Ana sigorta yuvası | Hepsiburada (allestock) | Allestock Kablolu Kapaklı Bıçak Sigorta Yuvası - Tekli | 495,00 | Stokta | https://www.hepsiburada.com/allestock-kablolu-kapakli-bicak-sigorta-yuvasi-tekli-pm-HBC00002M7LNF | 12 AWG, 30 A |
| 8 | Sigorta yuvası | Direnc.net | Sigorta Yuvası - Kablolu 30cm | 37,78 | Belirsiz | https://www.direnc.net/sigota-yuvasi-kablolu-30cm | 18 AWG, 30 A için ince |
| 9 | XT60 | Direnc.net | XT60 Plug 60A Li-Po Konnektör Takım | 21,50 / çift | Stokta | https://www.direnc.net/xt60-plug-60a-li-po-konnektor | |
| 9 | XT60 | Robotsepeti | XT60 Konnektör - Erkek / - Dişi | 21,01 + 21,61 | Stokta | https://www.robotsepeti.com/xt60-konnektor-erkek | |
| 10 | Ana anahtar | Motorobit | ASW-A01 100A ON-OFF Battery Disconnect Switch | 276,00 | Stokta (10+) | https://www.motorobit.com/asw-a01-100a-on-off-battery-disconnect-switch | |
| 10 | Ana anahtar | Motorobit | 56-00026 125A Battery Disconnect Switch | 156,00 | Stokta (10+) | https://www.motorobit.com/56-00026-125a-battery-disconnect-switch | |
| 11 | 12 AWG | Motorobit | 12 AWG Silicone Cable Red / Black - 1 Meter | 126,00 / m | Stokta | https://www.motorobit.com/12-awg-silicone-cable-red-1-meter | |
| 11 | 12 AWG | F1Depo | 12 AWG Silikon Kablo 1 Metre | 84,00 / m | Belirsiz | https://www.f1depo.com/urun/12-awg-silikon-kablo-1-metre-kirmizi-renk | |
| 11 | 18 AWG | Motorobit | 18 AWG Silicone Cable Red / Black - 1 Meter | 42,00 / m | Stokta | https://www.motorobit.com/18-awg-silicone-cable-red-1-meter | |
| 12 | 2200µF 16V | Motorobit | 2200uF 16V Electrolytic Capacitor 10x20mm | 4,20 | Stokta | https://www.motorobit.com/2200uf-16v-electrolytic-capacitor-10x20mm | |
| 12 | 2200µF 16V | Direnc.net | 2200uF 16V Kondansatör 10x20mm | 4,94 | Stokta | https://www.direnc.net/2200uf-16v | |
| 13 | Wago 221-413 | Trendyol (WAGO) | WAGO 221-413 3'lü (10 ADET) | 328,00 / 10'lu | Tükeniyor | https://www.trendyol.com/wago/221-413-3-lu-yayli-tirnakli-klemens-10-adet-p-1041174151 | |
| 13 | Wago 221-415 | Trendyol (WAGO) | WAGO 221-415 5'li Adet Fiyatı | 83,00 / adet | Son 1 ürün | https://www.trendyol.com/wago/221-415-5-li-yayli-tirnakli-klemens-adet-fiyati-p-43493710 | |
| 13 | Wago | Star Akım | Wago 221-413 / 221-415 | 20,07 / 31,80 adet | Stokta | https://www.starakim.com/buat-klemens-tirnakli-3-lu-122946 | 50'li / 25'li paket |
| 13 | Makaron | Direnc.net | 750 Parça Isı ile Daralan Makaron Paketi | 232,47 | Stokta | https://www.direnc.net/750-parca-isi-ile-daralan-makaron-paketi | |

### 2. Önerilen seçim (ajanın)

| # | Kalem | Satıcı | Birim TL | Adet | Toplam TL | Durum |
|---|---|---|---|---|---|---|
| 1 | DS3218MG | Robocombo | 959,40 | 4 (+1 yedek) | 3.837,60 (+959,40) | doğrulandı |
| 2 | MG996R (Tower Pro) | Robocombo | 197,78 | 6 (+2 yedek) | 1.186,68 (+395,56) | doğrulandı |
| 3 | BTS7960 | Direnc.net | 232,47 | 2 (+1 yedek) | 464,94 (+232,47) | doğrulandı |
| 4 | XL4016 8A | Motorobit | 240,00 | 3 | 720,00 | doğrulandı |
| 5 | LiFePO4 12,8V 24Ah | Limacell | 4.713,43 | 1 | 4.713,43 | doğrulandı (ölçü teyitsiz) |
| 6 | LiFePO4 şarj 6A | UserPil | 1.642,30 | 1 | 1.642,30 | doğrulandı |
| 7 | Emas B200E-E acil stop | Elektrix | 231,66 | 1 | 231,66 | doğrulandı |
| 8 | Sigorta kutusu + 2×30A + ana yuva | Motorobit / Hepsiburada | 309 + 4,20 + 495 | | 812,40 | doğrulandı |
| 9 | XT60 çift | Direnc.net | 21,50 | 5 | 107,50 | doğrulandı |
| 10 | Akü ayırıcı anahtar ASW-A01 | Motorobit | 276,00 | 1 | 276,00 | doğrulandı |
| 11 | 12 AWG 2+2 m, 18 AWG 5+5 m | Motorobit | 126 / 42 | | 924,00 | doğrulandı |
| 12 | 2200µF 16V | Motorobit | 4,20 | 4 | 16,80 | doğrulandı |
| 13 | WAGO 221-413 (10'lu) + 221-415 ×5 + makaron | Trendyol / Direnc | | | 975,47 | 221-415 stok yetersiz |
| | **Toplam** | | | | **17.496,21** (yedekler 1.587,43 dahil) | kargo hariç |

### 3. Kargo
Robocombo 2.000 TL (altında 150 TL). Motorobit 2.500 TL. Direnc 1.500 TL. Limacell "Kargo bedava". Elektrix 10.000 TL (ücretli).

### 4. Açık kalanlar
1. Akü: Limacell 24 Ah'ın ölçü, ağırlık, kasa tipi sayfada yok; sipariş üzerine üretim. 181×77×167 mm yuvaya sığdığı satıcıya sorulmalı. Ölçüsü tutan Orbus LIT-12-20 stokta yok.
2. UserPil şarj cihazı adında "14,4 V"; kesme gerilimi teyit edilmeli.
3. MG996R: orijinal Tower Pro'da bile iç dişliler plastik (Motorobit/Robotistan açıklaması).
4. DS3218MG: Robocombo dişli malzemesini belirtmiyor; 270° versiyonu TR'de yok.
5. XL4016: uzun süreli kullanımda 5 A öneriliyor; Pi 5 V/5 A hattı sınırda.
6. Ana sigorta yuvası pahalı (495 TL); ucuz alternatifler stokta yok.
7. Emas B200E60: Kartal sayfası "NO" diyor, üreticiye göre 1NC.
8. WAGO 221-415 Trendyol'da 1 adet; alternatif Star Akım 25'li paket.
9. XT60 Direnc 21,50 TL/çift diğerlerinin yarısı; Amass mı muadil mi teyit edilmeli.
10. Açılamayan: n11, Çiçeksepeti, Cimri, Akakçe, Trendyol'un bazı ürün sayfaları (403); Doğuş Elektrik, Komponentci, Saykil, Atakale (DNS).

## Ajan 4: 3D baskı, lazer kesim, hırdavat, kur, kargo

Hiçbir şey satın alınmadı, sepete eklenmedi, form gönderilmedi. Fiyatlar sayfadan veya sayfa kaynağındaki ürün verisinden (T-Soft `PRODUCT_DATA`, Shopify JSON, schema.org) okundu. Akakçe, Cimri, Trendyol, n11 ve Hepsiburada hem WebFetch hem curl ile **403** verdi.

### 1. Ham bulgular

| # | Kalem | Satıcı/kaynak | Ürün/hizmet | Fiyat TL (KDV dahil) | Stok | URL | Not |
|---|---|---|---|---|---|---|---|
| 1 | PETG | Microzey (resmi site) | PETG Siyah 1,75 mm 1 kg (HS PETG kategorisi) | **359,00** (liste 489, %27 indirim) | Var (quantity 145) | https://microzey.com/petg-siyah | KDV %20 dahil (sale_price 299,17 + KDV). Beyaz ve gri sayfaları 404. |
| 1 | PETG | Akakçe | Microzey PETG Siyah 1 kg | Açılmadı | – | https://www.akakce.com/filament/en-ucuz-microzey-petg-siyah-1-75mm-1-kg-fiyati,1676232605.html | 403. 565,28 TL'lik referans yeniden doğrulanamadı. |
| 1 | PETG | FilamentMarketim | Elas PETG 1,75 mm 1 kg siyah | **549,00** (havale 534,73) | InStock | https://www.filamentmarketim.com/elas-1.75-mm-siyah-petg-filament-1kg | Sayfada KDV ibaresi yok. 2.500 TL üzeri Elas alımında sepette ek %10 indirim var. |
| 1 | PETG | Ventatek | Filamix Hyper PETG Siyah 1 kg | **564,25** | "Kritik stok" | https://ventatek.com/filamix-hyper-petg-siyah-filament-1.75mm-1-kg | Schema fiyatı 470,21 KDV hariç, ×1,2 = 564,25 |
| 1 | PETG | FilamentMarketim | Filamix Hyper PETG (siyah/beyaz/gri) | **587,42** | Var | https://www.filamentmarketim.com/filamix-hyper-petg-filament | |
| 1 | PETG | Porima (resmi site) | Porima PETG Siyah RAL9005 1 kg / 3 kg | **673,44** / **2.014,56** | Var | https://porima3d.com/products/porima-petg-filament | "KDV dahildir" yazıyor |
| 1 | PETG | Robocombo | Porima PETG Beyaz 1 kg | 797,04 | **Yok** | https://www.robocombo.com/porima-petg-filament-1.75mm-beyaz-1kg-3587 | |
| 1 | PETG | Robolink | eSUN PETG Siyah 1 kg | 820,50 | **Yok** | https://www.robolinkmarket.com/esun-petg-filament-siyah-175mm-1000gr | |
| 1 | PETG | Robotsepeti | eSUN PETG Düz Siyah 1 kg | 873,49 | **Yok** | https://www.robotsepeti.com/esun-1-75mm-petg-duz-filament-siyah-1kg | |
| 2 | Baskı hizmeti | 3dprinterdestek | Rehber: "Türkiye'de… 0.50-2 TL/gram" | 0,50–2 TL/g | – | https://3dprinterdestek.com/3d-baski-maliyet-hesaplama | Kılavuz aralığı, firma teklifi değil |
| 2 | Baskı hizmeti | Yazdır Gelsin | STL yükleyip anında fiyat alınıyor | Sayfada TL/g yok. Kaynak koddaki malzeme tablosunda PETG `birim_fiyat` 0,85 (birimi yazmıyor) | – | https://yazdirgelsin.com/3d-baski-fiyati-hesapla | 2.000 TL üzeri kargo ücretsiz |
| 2 | Baskı hizmeti | Armut | 3D baskı ortalama fiyat | 500–4.000 / sipariş (200+ adet: 1.000–5.000) | – | https://armut.com/fiyatlari/3d-baski_12669 | Eylül 2026 |
| 3 | Al levha | Metal Reyonu | Alüminyum Levha 3 mm, alaşım 5754 | **395,00 TL/kg** | InStock | https://metalreyonu.com.tr/urun/aluminyum-levha-3-mm | KDV belirtilmemiş. Yalnız tam boy satılıyor, "özel boy kesimi yapılmamaktadır". |
| 3 | Al levha | Alüminyumburada | 5754-H111 3 mm | Fiyat görünmüyor ("₺ -,-") | Tam boy stok yok | https://aluminyumburada.com/aluminyum-levha/5754-H111-3mm | |
| 3 | Al kesim | Armut | Alüminyum lazer kesim | 1.000–5.000. Örnekler: 1.500 (300×300×4 mm, 17.09.2026), 500 (500×500×4 mm, 510 delik, 11.04.2026) | – | https://armut.com/fiyatlari/aluminyum-lazer-kesim_5918 | |
| 3 | Al kesim | lazermakine.com | Dakika fiyatı rehberi | Alüminyum ~40–50 TL/dk, ahşap ~20–35 TL/dk | – | https://lazermakine.com/lazer-kesim-dakikasi-kac-tl/ | 19.12.2025 tarihli |
| 3–4 | Online kesim | Cutmatik / KesiMAX / Robotistan / AKS / Lazerkesimci | DXF yükle, anında fiyat | Yayınlanmış birim fiyat yok | – | https://cutmatik.com/ · https://www.kesimax.com.tr/ · https://www.robotistan.com/lazer-kesim-servisi | Cutmatik fiyatları KDV hariç. Teklif için DXF gerekiyor, yüklenmedi. |
| 4 | Kontrplak | Lazerci | Huş 6 mm 76×76 cm | 7 EUR + KDV (≈467,8 TL, TCMB EUR 55,6880 ile) | Var | https://www.lazerci.com/kontrplak-urunleri?pg=1 | 5 mm yok |
| 4 | Kontrplak | iAhşap | Marin huş 4 mm 50×50 cm | 372,70 | Belirtilmemiş | https://www.iahsap.com/product-page/50x50-cm-kal%C4%B1nl%C4%B1k-18-mm-marin-hu%C5%9F-kontraplak-su-kontras%C4%B1-suya-dayan%C4%B1kl%C4%B1 | |
| 4 | Kontrplak | Kontrplaklar.com | Huş 4 mm 125×250 cm | 937,50 | Listelenmiş | https://kontrplaklar.com/hus | KDV belirsiz, 5 mm yok |
| 4 | Ahşap kesim | Armut | Ahşap lazer kesim | 250–1.800. Örnek: 40×40 cm kontrplak şablon 500 TL | – | https://armut.com/fiyatlari/ahsap-lazer-kesim_46788 | |
| 5 | Civata seti | Robolink | M3 YSB vida-somun-pul 220 parça | **411** | Var (7) | https://www.robolinkmarket.com/m3-ysb-vida-somun-ve-pul-seti-220-parca | Malzeme belirtilmemiş |
| 5 | Civata seti | Robolink | M4 YSB 395 parça | **657** | Var (8) | https://www.robolinkmarket.com/m4-ysb-vida-somun-ve-pul-seti-395-parca | Malzeme belirtilmemiş |
| 5 | Civata seti | Robolink | M5 YSB 188 parça | **363** | Var (4) | https://www.robolinkmarket.com/m5-ysb-vida-somun-ve-pul-seti-188-parca | Malzeme belirtilmemiş |
| 5 | Civata seti | Amazon.com.tr (Ayaz Bağlantı) | YSB Vida Seti M3 M4 M5, 1533 parça (3 kutu) | 1.885,15 | Var | https://www.amazon.com.tr/dp/B0HC453JDQ | "Alaşım çelik", teslimat ücretsiz |
| 5 | Civata seti | Amazon.com.tr (NetzerHırdavat) | Netzerkoz 855 adet M3–M6 YHB vida-somun-pul | 999,00 | 10 adet kaldı | https://www.amazon.com.tr/dp/B0GYXRZBRB | Malzeme "Demir". Havşa baş. |
| 5 | Civata seti | Amazon.com.tr (Ayaz) | M3 imbus paslanmaz 500 p / M4 imbus paslanmaz 335 p (DIN 912 A2-70) | 948,53 / 954,67 | Var | https://www.amazon.com.tr/dp/B0HBQ57BNF · https://www.amazon.com.tr/dp/B0HBPV3B4P | |
| 5 | Civata seti | Amazon.com.tr (Site Hırdavat) | M5 imbus civata-somun-rondela 284 p | 1.067,06 | 2–3 günde kargo | https://www.amazon.com.tr/dp/B08DFZPC98 | Malzeme belirtilmemiş |
| 5 | M3 burç | Direnc.net | Siyah M3 distans seti 200 parça (plastik) | **261,53** | Var (16) | https://www.direnc.net/siyah-m3-distans-vida-seti-200-parca | |
| 5 | M3 burç | Motorobit | 100 parça M3 siyah plastik aralayıcı | **360,00** | Var (24) | https://www.motorobit.com/100-piece-m3-black-plastic-spacer-set-standoff | Schema'daki 300,00 KDV hariç |
| 5 | M3 burç | Voltaj | M3 metal stand-off seti | 301,93 | 20+ | https://www.voltaj.net/araliyici-distans-m3-stand-off-seti-pmu35985 | KDV durumu belirsiz |
| 5 | M3 burç | Robotistan | 200 adet M3 plastik siyah | 322,67 | **Tükendi** | https://www.robotistan.com/200-adet-m3-plastik-siyah-mesafe-burcu-seti | |
| 5 | M3 burç | Robo90 | 120 adet M3 pirinç distans kutulu | 347,76 | **Yok** | https://www.robo90.com/120-adet-m3-distans-standoff-seti-kutulu | |

### 2. Önerilen tablo

| # | Kalem | Seçim | Birim | Miktar | Toplam TL | URL | Durum |
|---|---|---|---|---|---|---|---|
| 1 | PETG | Microzey PETG Siyah 1 kg | 359,00 | 5 | **1.795,00** | https://microzey.com/petg-siyah | doğrulandı (kargo belirsiz) |
| 3 | Al kesim | Lazer atölyesi: 3 mm 5754 plaka + küçük parçalar + 2 büküm | set | 1 | **1.500** (aralık 1.000–2.000) | Armut ve lazermakine referansları | tahmini |
| 4 | Kontrplak kesim | 5 mm huş (yoksa 4 veya 6 mm), 340×500 delikli | adet | 1 | **500** (aralık 400–700) | Armut ahşap örneği | tahmini |
| 5 | Civata | Robolink M3 + M4 + M5 YSB setleri | 411 + 657 + 363 | 1'er | **1.431,00** | Yukarıdaki Robolink URL'leri | doğrulandı |
| 5 | M3 burç | Direnc.net siyah M3 200 parça | 261,53 | 1 | **261,53** | https://www.direnc.net/siyah-m3-distans-vida-seti-200-parca | doğrulandı |
| | **Toplam (yazıcı varsa)** | | | | **≈5.487,53 TL ≈ 112,3 USD** (48,8780 ile), kargo hariç | | |
| 2 | *Alternatif: bölümde yazıcı yoksa* | PETG baskı hizmeti, 1,5 TL/g | 1,5 TL/g | 3.700 g | **≈5.550** (aralık 3.700–7.400) | https://3dprinterdestek.com/3d-baski-maliyet-hesaplama | tahmini, 1. satırın yerine geçer (toplam ≈9.242,53 TL) |

**Gerekçe ve hesaplar**
- **Filament:** Stoktaki en ucuz seçenek Microzey. %27'lik indirim kampanya fiyatı, bitebilir. Yedek plan Elas: 5 × 549 = 2.745 TL, 2.500 TL üzeri %10 indirimle 2.470,50 TL, kargo ücretsiz. Porima 3 kg + 2 × 1 kg = 3.361,44 TL.
- **Alüminyum:** 340×500×3 mm = 510 cm³ × 2,67 g/cm³ ≈ **1,36 kg**. Küçük parçalar 26,9 cm³ ≈ 0,07 kg. Toplam **≈1,43 kg**. Malzeme: 1,43 × 395 ≈ 566 TL; %30 fire ile ≈735 TL; fiyat KDV hariçse ≈880 TL. Kesim yolu ≈3,3 m, ≈27 delgi; makine süresi birkaç dakika × 40–50 TL/dk ≈ 150–250 TL. Hazırlık ücreti, asgari iş bedeli ve büküm eklenince Armut örnekleriyle (500–1.500 TL) birlikte 1.000–2.000 TL.
- **Kontrplak:** Malzeme 4 mm tam levhadan orantılanırsa ≈51 TL; 6 mm 76×76 levha ≈468 TL. Kesim ≈2,4 m, CO₂ lazerle 3–5 dk × 20–35 TL/dk. Asgari iş bedeli baskın; Armut'taki 40×40 cm şablon örneği 500 TL.
- **Baskı hizmeti:** 3,7 kg × 1–2 TL/g. Yazdır Gelsin'in PETG parametresi (0,85, büyük olasılıkla TL/g) yalnız malzeme payı gibi duruyor; süre ücreti ayrıca ekleniyor.
- **Civata:** Robolink setleri en ucuz, stokta ve KDV dahil, ama malzeme belirtilmemiş. Paslanmaz imbus yolu: Amazon'da M3 + M4 + M5 toplamı 2.970,26 TL. Tek kutu: Ayaz YSB M3/M4/M5, 1.885,15 TL.

### 3. Kur (USD/TRY)

| Kaynak | Tarih | Değer | URL |
|---|---|---|---|
| **TCMB döviz satış** | 25.09.2026, bülten 2026/181 | **48,8780** (döviz alış 48,7901, efektif satış 48,9514) | https://www.tcmb.gov.tr/kurlar/202609/25092026.xml |
| TCMB today.xml | Hâlâ 25.09.2026'yı gösteriyor | 48,8780 | https://www.tcmb.gov.tr/kurlar/today.xml |
| Investing (TR) Cuma kapanışı | 25 Eyl 2026 | **48,9496** (açılış 48,8780 / yüksek 49,1377 / düşük 48,6030) | https://tr.investing.com/currencies/usd-try-historical-data |
| Yahoo Finance (çapraz kontrol) | 25.09 günlük kapanış | 48,9494 | https://query1.finance.yahoo.com/v8/finance/chart/TRY=X?interval=1d&range=1mo |

EUR döviz satış 55,6880 (TCMB, 25.09). Öneri: TCMB döviz satış 48,8780. Serbest piyasayla fark yaklaşık %0,15.

### 4. Kargo

| Satıcı | Ücretsiz kargo eşiği | Eşik altı ücret | Kaynak |
|---|---|---|---|
| Robotistan | 1.500 TL (Yurtiçi/Aras) | Sayfada yok, sepette görünüyor | https://www.robotistan.com/kargo-ve-teslimat |
| Direnc.net | 1.500 TL ("Kargo Bedava" bandı) | Sayfada yok | https://www.direnc.net/ |
| Robolink Market | 1.500 TL, KDV dahil (SSS: "DHL için") | DHL 89,90 / HepsiJet 119 / Aras 139 | https://www.robolinkmarket.com/teslimat-kosullari |
| Robotsepeti | Sitede bulunamadı | Bulunamadı | https://www.robotsepeti.com/teslimat-kosullari.shtm |
| Motorobit | 2.500 TL (MNG-DHL) | Sayfada yok | https://www.motorobit.com/ |
| Microzey | Bant 2.000 TL, teslimat sayfası 1.500 TL (çelişkili) | "Alıcıya aittir", tutar yok | https://microzey.com/teslimat-kosullari |
| FilamentMarketim | 1.500 TL | "109 TL'den başlar" | Elas ürün sayfası |
| Porima / Ventatek / Yazdır Gelsin | 1.500 / 3.000 / 2.000 TL | – | İlgili sayfalar |

### 5. Açık kalanlar
- Microzey kargosu: 1.795 TL'lik sipariş 1.500 ile 2.000 TL arasında; hangi eşik geçerli belli değil. 6. makara eklenirse (2.154 TL) iki kurala göre de ücretsiz.
- Akakçe referansı (565,28 TL) 403 yüzünden yeniden doğrulanamadı. Trendyol, Hepsiburada ve Cimri de açılmadı.
- Alüminyum ve kontrplak kesimi tamamen tahmini. Net fiyat için DXF'i KesiMAX, Cutmatik veya Robotistan lazer servisine yükleyip anında teklif almak gerekiyor (Cutmatik KDV hariç veriyor). Delik çapı ve kesik ölçüleri varsayım.
- 5 mm huş bulunamadı; piyasada 4 veya 6 mm yaygın, kalınlık kararı verilmeli.
- Metal Reyonu 395 TL/kg'nin KDV durumu yazmıyor ve yalnız tam levha satılıyor; yalnız referans.
- Civata malzemesi Robolink ve Ayaz YSB setlerinde belirtilmemiş. Paslanmaz şartsa imbus setler (≈2.970 TL).
- Baskı hizmeti: gerçek fiyat için STL'leri Yazdır Gelsin'e yükleyip teklif almak gerekiyor; baskı hacmi ayrıca kontrol edilmeli.
- Eşik altı kargo ücretleri Robotistan, Direnc ve Motorobit'te sepete eklemeden görülemiyor.

## 4. V2 eklemeleri (2 Ekim 2026)

Hocanın geri bildirimiyle 7" yüz ekranı kalktı; göğüse 10,1" ekran, kafaya iki yuvarlak göz ekranı girdi. Araştırmayı bir
Claude Opus alt ajanı yaptı; orkestratör seçilen iki ürünün fiyatını ve stoğunu sayfanın JSON-LD verisinden yeniden okudu.

| Kalem | Satıcı | Sayfa verisi | KDV dahil | Stok |
|---|---|---|---|---|
| Waveshare 10.1" HDMI LCD (B) kasalı, 1280 × 800 | Robotsepeti | `price` 10272.51 (KDV hariç) | 12.327,01 TL | InStock |
| Waveshare 1.28" yuvarlak LCD (GC9A01), ×2 | Robotistan | `price` 863.43 (KDV dahil) | 863,43 TL | InStock |
| Alternatif: Waveshare 10.1" (E), 1024 × 600 | Robotistan | `price` 6607.48 | 6.607,48 TL | InStock (alt ajan) |
| Alternatif: GC9A01 muadil, çizimi yok | Motorobit | `price` 450.00 (KDV hariç) | 540,00 TL | InStock (alt ajan) |

- Direnc.net'teki 10,1" 1280 × 800 muhafazalı ekran `OutOfStock` (7.807,92 TL KDV dahil).
- 10,1" ekran ayrı 5 V besleme ister: arka ışık açıkken ≈ 750 mA (Waveshare wiki SSS). Dokunmatik için USB kablosu gerekir.
  Paketten HDMI ve USB kablosu çıkıp çıkmadığı doğrulanmadı.
- Filament: V2 baskı parçaları CAD'den ≈ 4,4 kg (V1 ≈ 3,7 kg) → V2'de 6 × 1 kg.
- Daha büyük SPI yuvarlak ekran bulunamadı (Robotistan 3,4" yuvarlak HDMI arabirimli, 5.408,83 TL).

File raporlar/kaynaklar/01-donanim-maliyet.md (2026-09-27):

---
title: "Kanıt: Donanım ve maliyet"
created: 2026-09-26
---

> Claude Opus alt ajan raporu, 26 Eylül 2026, olduğu gibi. Rakamlar ajanın beyanıdır; "(t)", "tahmini", "doğrulanmadı" işaretleri korunmuştur.

# Tekerlekli insansı robot: donanım ve maliyet araştırması (Eylül 2026)

**Fiyatlar hakkında:** TL fiyatları KDV dahildir ve 26.09.2026'da mağaza sayfalarından tek tek kontrol ettim. Kur varsayımı **1 USD ≈ 49 TL** (Investing, 26.09.2026 aralığı 48,77–49,01). "(t)" işareti tahmin demek: ya doğrulanmış bir TR fiyatı bulamadım ya da global fiyatı çevirdim. **Önemli:** Robotistan ve Robolink'teki çoğu kalem (Pi 5, JGB37, MG996R, BTS7960, DS3218, Jetson, Pi Cam 3) kontrol anında **"Tükendi"** görünüyordu. Alışverişten önce stok ve fiyata tekrar bakın.

## 1) MİNİMUM: yalnız ses, 2 DoF'lu basit kollar, ~10-15 kg

| Kalem | Model | Adet | Birim (TL) | Toplam (TL) | Kaynak |
|---|---|---|---|---|---|
| Tahrik motoru | JGB37-520 12V enkoderli (60-110 RPM) | 2 | 639,29 | 1.278,58 | Direnc.net |
| Motor sürücü | BTS7960B 43A | 2 | 227,31 | 454,62 | Direnc.net |
| Tekerlek | 125×58 mm arazi tekerleği | 2 | 353,63 | 707,26 | Robotistan |
| Kaplin 6 mm | metal göbek | 2 | 150 (t) | 300 | — |
| Sarhoş teker | 50 mm tablalı | 2 | 75 | 150 | Yollabize |
| Şasi | 4-6 mm kontrplak, lazer kesim (~5 TL/dk) | 1 | 1.000 (t) | 1.000 | Dönmez Reklam İzmir |
| Kol + kafa servo | MG996R (9,4-11 kg·cm, stall 2,5 A) | 6 | 230,99 | 1.385,94 | Robotistan |
| Servo sürücü | PCA9685 16 kanal | 1 | 345 | 345 | Robolink |
| Göz | 0,96" OLED | 2 | 150 (t) | 300 | — |
| Ana işlemci | Raspberry Pi 5 8GB | 1 | 11.966,22 | 11.966,22 | Robotistan |
| SD + soğutucu | — | 1 | 600 (t) | 600 | — |
| Alt kontrolcü | ESP32-WROOM-32D | 1 | 275,22 | 275,22 | Direnc.net |
| Mikrofon | USB konferans mikrofonu | 1 | 800 (t) | 800 | — |
| Amfi + hoparlör | PAM8403 + 2×3W | 1 | 120,15 (t) | 120,15 | Robotistan (amfi 20,15) |
| Mesafe sensörü | HC-SR04 | 3 | 60 (t) | 180 | — |
| Acil stop | Emas B200E60, 22 mm, kalıcı | 1 | 308,88 | 308,88 | Akakçe |
| Batarya | LiPo 4S 5200 mAh 40C | 1 | 3.147,60 | 3.147,60 | F1Depo |
| Denge şarj cihazı | iMax B6 sınıfı | 1 | 1.800 (t) | 1.800 | — |
| DC-DC | XL4016 (servo 6V + Pi 5V) | 2 | 250 (t) | 500 | — |
| Sigorta, XT60, anahtar, kablo | — | 1 set | 800 (t) | 800 | — |
| Filament | Microzey PETG 1 kg | 3 | 565,28 | 1.695,84 | Akakçe (25.09.2026) |
| Vida, somun, rulman | — | 1 set | 1.000 (t) | 1.000 | — |
| Yedek | 2 MG996R + 1 BTS7960 | — | — | 689,29 | — |
| **Ara toplam** | | | | **29.805** | |
| **+%25 beklenmeyen (kargo, tekrar baskılar)** | | | | **7.451** | |
| **TOPLAM** | | | | **≈ 37.250 TL ≈ 760 USD** | |

## 2) ORTA: ses + görüntü, kol başına 4 DoF, ~15-20 kg

| Kalem | Model | Adet | Birim (TL) | Toplam (TL) | Kaynak |
|---|---|---|---|---|---|
| Taban (motor + sürücü + tekerlek + kaplin + sarhoş teker) | Minimumdaki gibi | — | — | 2.890,46 | yukarıdaki |
| Şasi | 40×40 sigma, 2 m (834 TL/m) + köşe bağlantı + lazer kesim tabla | — | — | 3.268 (kısmen t) | Robolink |
| Omuz servosu | DS3218MG 20 kg·cm | 4 | 1.594,50 | 6.378 | Robolink |
| Dirsek/el servosu | MG996R | 4 | 230,99 | 923,96 | Robotistan |
| Kafa pan-tilt | MG996R | 2 | 230,99 | 461,98 | Robotistan |
| Servo sürücü | PCA9685 | 1 | 345 | 345 | Robolink |
| Yüz ekranı | Waveshare 7" HDMI 1024×600 | 1 | ~59,68 USD → 2.924 | 2.924 | Robotistan (USD fiyatlı) |
| Ana işlemci | Raspberry Pi 5 8GB + aktif soğutucu + NVMe/SD | 1 | 11.966 + 1.200 (t) | 13.166,22 | Robotistan |
| Alt kontrolcü | ESP32 | 1 | 275,22 | 275,22 | Direnc.net |
| Kamera | Raspberry Pi Camera Module 3 | 1 | 1.791,36 | 1.791,36 | Robotistan |
| Mikrofon | USB konferans mikrofonu | 1 | 1.500 (t) | 1.500 | — |
| Ses | MAX98357 I2S amfi + hoparlör | 1 | 300 (t) | 300 | — |
| IMU | BNO055 (global 15-34 USD) | 1 | 980 (t) | 980 | Walmart/eBay |
| Ultrasonik + acil stop | — | — | — | 548,88 | — |
| Batarya | LiFePO4 12,8V 20Ah | 1 | 4.500 (t)* | 4.500 | *100Ah modeli 15.429 TL, Akakçe |
| LiFePO4 şarj cihazı | 14,6V | 1 | 800 (t) | 800 | — |
| DC-DC | 2× servo hattı + 1× Pi 5V/5A | 3 | 250 (t) | 750 | — |
| Sigorta ve kablo | — | 1 set | 1.200 (t) | 1.200 | — |
| Filament + hırdavat | PETG 5 kg + vida/rulman | — | — | 4.326,40 | Akakçe |
| Yedek | 1 DS3218 + 2 MG996R | — | — | 2.056,48 | — |
| **Ara toplam** | | | | **49.386** | |
| **TOPLAM (+%25)** | **Pi 5 ile** | | | **≈ 61.700 TL ≈ 1.260 USD** | |
| **TOPLAM (+%25)** | **Jetson Orin Nano Super ile** (31.282,50 TL, Robolink; Robot Sepeti'nde 40.703 TL) | | | **≈ 85.900 TL ≈ 1.750 USD** | |

## 3) İDDİALI: derinlik kamera, LiDAR, akıllı servolar, otonom gezinme, ~20-25 kg

| Kalem | Model | Adet | Birim (TL) | Toplam (TL) | Kaynak |
|---|---|---|---|---|---|
| Tahrik | 6,5" hoverboard göbek motoru | 2 | 2.450 (tükendi) | 4.900 | Trendyol |
| Sürücü | 2. el hoverboard kartı + FOC firmware (ODrive global ve pahalı) | 1 | 1.000 (t) | 1.000 | — |
| Sarhoş teker | 75-100 mm | 2 | 200 (t) | 400 | — |
| Şasi | Sigma 4 m + bağlantı + 3 mm Al sac lazer kesim | — | — | 7.036 (kısmen t) | Robolink |
| Akıllı servo | Feetech STS3215 (19,5 kg·cm, 20 USD) + ithalat | 10 | 1.470 (t) | 14.700 | Seeed Studio |
| Bus servo kartı | Seri servo sürücü | 1 | 700 (t) | 700 | — |
| Yüz ekranı | 7" HDMI | 1 | 2.924 | 2.924 | Robotistan |
| Ana işlemci | Jetson Orin Nano Super + NVMe | 1 | 31.282,50 + 1.500 (t) | 32.782,50 | Robolink |
| Alt kontrolcü | ESP32 | 1 | 275,22 | 275,22 | Direnc.net |
| Derinlik kamera | OAK-D Lite (269 USD) + kargo/vergi | 1 | 17.000 (t) | 17.000 | Luxonis |
| LiDAR | Slamtec RPLIDAR C1 | 1 | 4.510,85 | 4.510,85 | Robotistan |
| Mikrofon dizisi | ReSpeaker Mic Array v2.0 (USB) | 1 | 8.058,39 | 8.058,39 | Robot Sepeti |
| Ses, IMU, ToF, acil stop | — | — | — | 2.188,88 (t) | — |
| Batarya (24V) | 2× LiFePO4 12,8V 20Ah, seri | 2 | 4.500 (t) | 9.000 | — |
| Şarj cihazı, DC-DC, kontaktör, kablo | — | — | — | 4.200 (t) | — |
| Filament + hırdavat | PETG 8 kg + vida/rulman | — | — | 7.022,24 | Akakçe |
| Yedek | 2 STS3215 | — | — | 2.940 | — |
| **Ara toplam** | | | | **119.638** | |
| **TOPLAM (+%25)** | | | | **≈ 149.500 TL ≈ 3.050 USD** | |

Alternatifler: RealSense D435 38.260 TL (Robot Sepeti, stokta yok), Dynamixel XL430 2.905,64 TL/adet (Robot Sepeti, 10 adet ≈ 29.000 TL).

**Serbestlik derecesi (DoF) başına maliyet:** MG996R ≈ 230 TL, DS3218 ≈ 1.595 TL, STS3215 ≈ 1.470 TL (tahmini, ithal), XL430 ≈ 2.906 TL. Akıllı servolar konum, akım ve sıcaklık geri bildirimi verir. Bu sayede servo yanmadan önce fark edilir.

## Hangi beyin hangi senaryoya yeter?
- **Senaryo A (sadece ses):** Pi 5 fazlasıyla yeter. Uyandırma kelimesi cihazda çalışır, konuşmayı metne çevirme (STT), dil modeli ve metni sese çevirme (TTS) bulutta yapılır. Ekibin eski bir dizüstü bilgisayarı da iş görür ve maliyeti sıfırdır.
- **Senaryo B (ses + görüntü):** Pi 5 yüz algılamayı düşük çözünürlükte yapar ama YOLO ile kişi takibi yalnız CPU'da birkaç FPS'te kalır. Pi 5'e yapay zekâ hızlandırıcı eklemek bir seçenek, fiyatına bakmadım. Jetson Orin Nano Super (67 TOPS, 7-25 W) ise yüz, nesne ve takibi aynı anda gerçek zamanlı yapar. Intel N100 mini PC x86 kolaylığı sunar ama TR fiyatını doğrulayamadım. ESP32 ya da Arduino Mega yalnız motor PID'i, enkoder ve servo zamanlaması için kullanılmalı.
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

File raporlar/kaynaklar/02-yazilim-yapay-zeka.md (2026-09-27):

---
title: "Kanıt: Yazılım ve yapay zekâ"
created: 2026-09-26
---

> Claude Opus alt ajan raporu, 26 Eylül 2026, olduğu gibi. Rakamlar ajanın beyanıdır; "(t)", "tahmini", "doğrulanmadı" işaretleri korunmuştur.

# Tekerlekli insansı robot: yazılım ve yapay zekâ araştırması (Eylül 2026)

## Önce, işin gidişatını değiştiren beş bulgu
1. **Türkçe uyandırma kelimesi için hazır, ücretsiz bir çözüm yok.** Porcupine'in desteklediği diller arasında Türkçe yok; Türkçe yalnızca ticari müşterilere, duruma göre veriliyor. openWakeWord ise resmî olarak yalnızca İngilizce destekliyor. Fuar için en sağlam çözüm **bas-konuş düğmesi ya da dokunmatik sensör, yanında LED halka**. Yedek olarak "hey jarvis" gibi İngilizce bir hazır model de kullanılabilir.
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

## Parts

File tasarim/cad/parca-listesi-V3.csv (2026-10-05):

Parça | Model / malzeme | Ölçü (mm) | Adet | Birim kütle (g) | Toplam (g)
LiFePO4 12,8 V 20 Ah akü (yatık) | LiFePO4 12.8V 20Ah, BMS'li | 181 x 167 x 77 | 1 | 2800 | 2800
Şase uzun rayı | 40x40 agir sigma profil, kanal 10 | 40 x 40 x 500 | 2 | 995 | 1990
Taban eteği V3 (tekerlekleri sarar, yukarı daralır), PETG 3D baskı (6 parça) | PETG, 2,5 mm duvar, alt açık, yerden 35 mm | 443 (üstte 300) x 227 x 520 | 1 | 1965 | 1965
Gövde direği | 40x40 agir sigma profil, kanal 10 | 40 x 40 x 800 | 1 | 1593 | 1593
Gövde kabuğu V3 (eğik göğüs ekranı), PETG 3D baskı (8 parça) | PETG, 2,5 mm duvar | 304 x 723 x ~205 | 1 | 1524 | 1524
Şase ara rayı | 40x40 agir sigma profil, kanal 10 | 40 x 40 x 190 | 3 | 378 | 1134
Alt plaka V3, 3 mm alüminyum (lazer kesim) | 3 mm Al 5754, lazer kesim | 270 x 500 x 3 | 1 | 1052 | 1052
JGB37-520 enkoderli motor (60 dev/dk) | JGB37-520 12V, enkoderli | O37 redüktör, toplam ~64 + 15 mil | 4 | 200 | 800
10,1" HDMI LCD (göğüs ekranı) | Waveshare 10.1inch HDMI LCD (B), 1280×800 kapasitif (ölçü dogrulandi; kütle tahmini) | 254 x 169 x ~18 | 1 | 600 | 600
125 x 58 mm arazi tekerleği | Büyük arazi tekerleği 125x58 (mavi jant) | O125 x 58 | 4 | 140 | 560
Kafa kabuğu, PETG 3D baskı (2 parça) | PETG, 2,5 mm duvar | 210 x 180 x 150 | 1 | 492 | 492
Elektronik katı V3, 5 mm kontrplak (lazer kesim) | 5 mm huş kontrplak, lazer kesim | 270 x 500 x 5 | 1 | 423 | 423
Omuz traversi | 40x40 agir sigma profil, kanal 10 | 40 x 40 x 200 | 1 | 398 | 398
MG996R servo (≈10 kg·cm) | MG996R + disk horn | 40.7 x 19.7 x 36.6 | 6 | 55 | 330
40x40 geniş köşe bağlantı | 40x40 geniş köşe bağlantı + T somun | 37 x 37 x 37,7 | 4 | 75 | 300
DS3218MG servo (20 kg·cm) | DS3218MG + alüminyum disk horn | 40.0 x 20.0 x 40.4 | 4 | 60 | 240
7" HDMI LCD 1024x600 | Waveshare 7inch HDMI LCD (C) muadili | 164.9 x 124.25 x ~15 | 1 | 230 | 230
XL4016 DC-DC düşürücü | XL4016 8A modül | 65.0 x 47.0 x 23.5 | 3 | 60 | 180
12 mm altıgen kaplin (6 mm mil) | 12 mm altıgen pirinç kaplin, O6 delik | 12 AA x 30 | 4 | 35 | 140
BTS7960 43A motor sürücü | BTS7960B modülü | 50.0 x 50.0 x 43.0 | 2 | 66 | 132
JGB37 L montaj braketi | 37 mm motor L braketi (JGB37 delik duzeni kontrol!) | 46 x 42 x 40, 1,5 mm | 4 | 30 | 120
Etek taşıyıcı L braket, 2 mm Al | 2 mm Al, büküm | 114 x 32 x 30 | 4 | 23 | 93
Ön kol tüpü, PETG | PETG | O60 x 75 | 2 | 43 | 86
Üst kol tüpü, PETG | PETG | O56 x 80 | 2 | 43 | 85
22 mm mantar acil stop butonu | Emas B200E60 (O60 mantar, kalıcı) | O60, ön 28, arka 48 | 1 | 85 | 85
Dirsek kapağı, PETG | PETG | O56 x 56 | 2 | 35 | 70
El, PETG (sabit, %30 doluluk) | PETG, %30 doluluk | 26 x 62 x 50 | 2 | 35 | 70
Omuz kapağı, PETG | PETG | O76 | 2 | 32 | 63
Raspberry Pi 5 8GB + Active Cooler | Raspberry Pi 5 8GB | 85 x 56 x ~18 | 1 | 58 | 58
M5 x 40 mesafe burcu | M5 x 40 pirinç burç | M5 x 40 | 4 | 12 | 48
Kafa taşıyıcı plaka, PETG | PETG, %40 doluluk | 120 x 90 x 4 | 1 | 40 | 40
Boyun plakası, 3 mm alüminyum | 3 mm Al | 70 x 70 x 3 | 1 | 39 | 39
Servo kızağı (2 mm alüminyum) | 20 kg servo için çok amaçlı braket | 24 x 44 x 30 | 2 | 19 | 38
Kol bağlantı plakası, 2 mm Al | 2 mm Al | 24 x 32 x 8 | 2 | 17 | 33
Yüz paneli, 3 mm parlak siyah akrilik (lazer kesim) | 3 mm siyah akrilik, ekran penceresi | 190 x 115 x 3 | 1 | 28 | 28
40 mm 3 W hoparlör | 40 mm 4 ohm 3 W | O40 x 18 | 1 | 27 | 27
HC-SR04 ultrasonik sensör | HC-SR04 | 45 x 20 x 15 | 3 | 9 | 27
Omuz bağlantı plakası, 2 mm Al | 2 mm Al | 76 x 30 x 2 | 2 | 12 | 25
Kafa eğme U braketi, 2 mm Al | Uzun U servo braketi | 50 x 48 x 24 | 1 | 18 | 18
ESP32-WROOM-32D DevKit | ESP32 DevKit 30 pin | 52.0 x 28.0 | 1 | 10 | 10
PCA9685 16 kanal servo sürücü | PCA9685 (Adafruit tipi) | 62.2 x 25.4 | 1 | 9 | 9
Raspberry Pi Camera Module 3 | Camera Module 3 (12 MP) | 25 x 24 x 11,5 | 1 | 4 | 4
BNO055 IMU kartı | BNO055 | 27.0 x 20.0 | 1 | 3 | 3
MAX98357A I2S amfi | MAX98357A | 19.4 x 17.8 | 1 | 2 | 2
Vida, somun, T-somun, kablo payı | tahmini |  | 1 | 600 | 600
TOPLAM |  |  |  |  | 18567

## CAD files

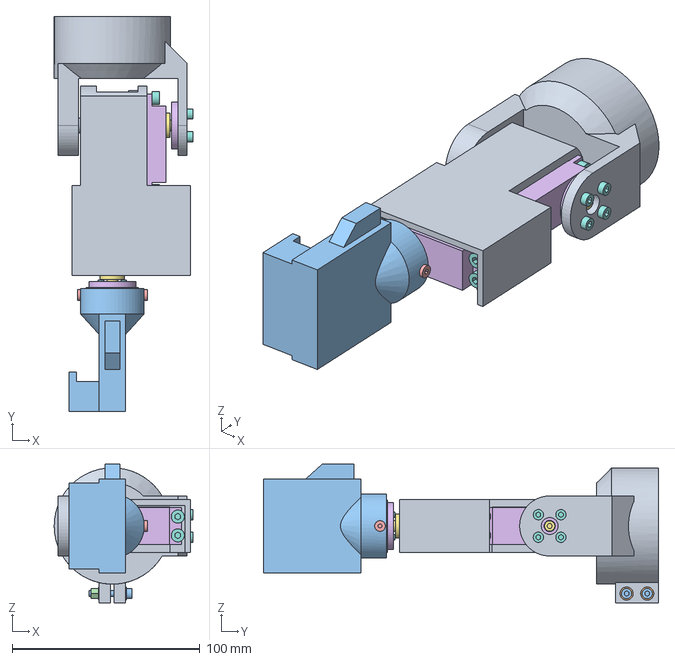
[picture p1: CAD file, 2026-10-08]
tasarim/freecad/dirsek/dirsek-montaj.step
73.9 x 210.5 x 74.0 mm

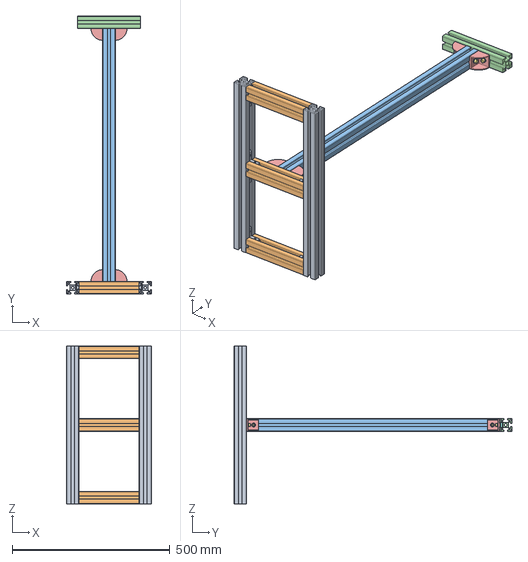
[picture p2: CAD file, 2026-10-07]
tasarim/freecad/iskelet/iskelet-montaj.step
270.0 x 880.5 x 500.0 mm

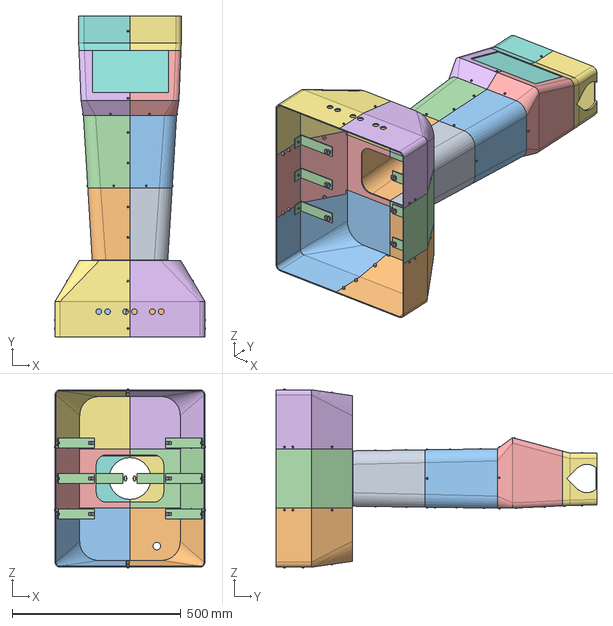
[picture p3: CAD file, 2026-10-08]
tasarim/freecad/kabuk/kabuk-montaj.step
447.4 x 950.0 x 528.4 mm

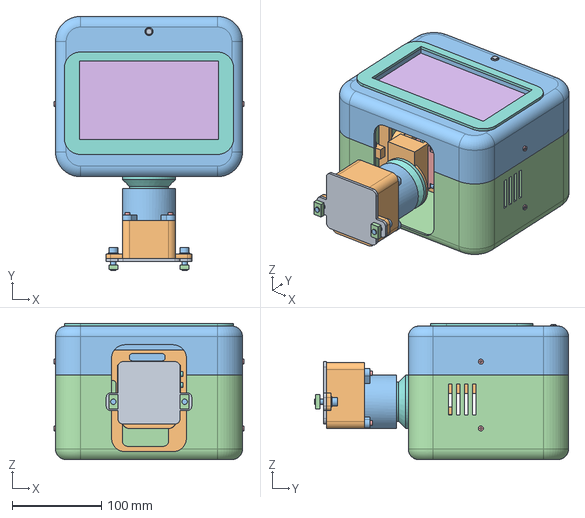
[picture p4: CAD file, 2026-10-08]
tasarim/freecad/kafa/kafa-montaj.step
213.3 x 285.4 x 153.0 mm

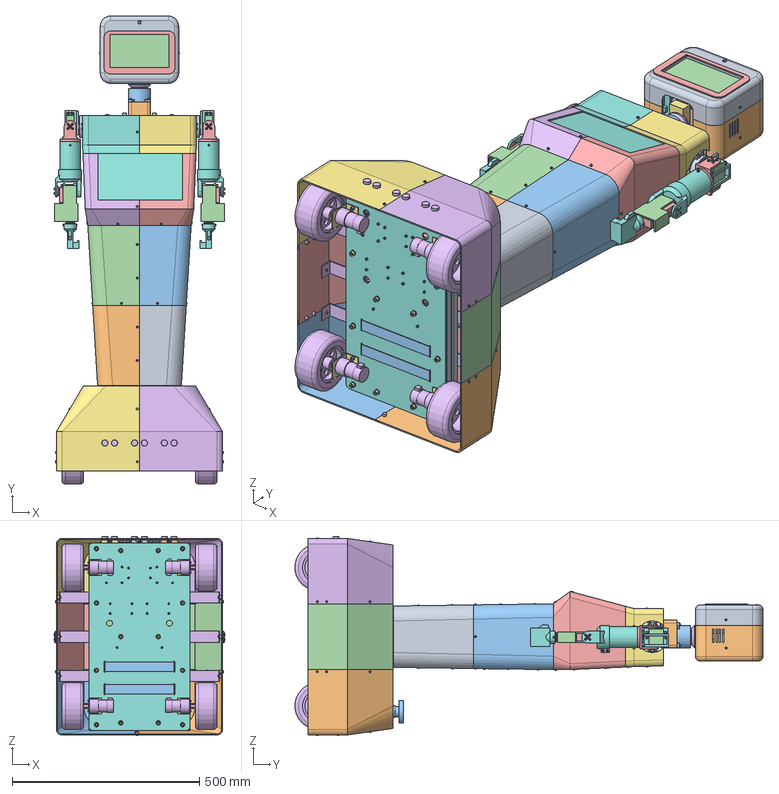
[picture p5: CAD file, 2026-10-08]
tasarim/freecad/montaj/robot-montaj.step
455.8 x 1249.5 x 532.2 mm
Sase uzun rayi sag
Sase uzun rayi sol
Sase ara rayi arka
Sase ara rayi orta
Sase ara rayi on
Govde diregi
Omuz traversi
Kose baglanti 40x40 genis (Direk-ray sag)
Pul M6 (Direk-ray sag, ayak A)
Civata M6x16 (Direk-ray sag, ayak A)
Cekic somun M6 (Direk-ray sag, ayak A)
Pul M6 (Direk-ray sag, ayak B)
Civata M6x16 (Direk-ray sag, ayak B)
Cekic somun M6 (Direk-ray sag, ayak B)
Kose baglanti 40x40 genis (Direk-ray sol)
Pul M6 (Direk-ray sol, ayak A)
Civata M6x16 (Direk-ray sol, ayak A)
Cekic somun M6 (Direk-ray sol, ayak A)
Pul M6 (Direk-ray sol, ayak B)
Civata M6x16 (Direk-ray sol, ayak B)
Cekic somun M6 (Direk-ray sol, ayak B)
Kose baglanti 40x40 genis (Direk-travers sag)
Pul M6 (Direk-travers sag, ayak A)
Civata M6x16 (Direk-travers sag, ayak A)
Cekic somun M6 (Direk-travers sag, ayak A)
Pul M6 (Direk-travers sag, ayak B)
Civata M6x16 (Direk-travers sag, ayak B)
Cekic somun M6 (Direk-travers sag, ayak B)
Kose baglanti 40x40 genis (Direk-travers sol)
Pul M6 (Direk-travers sol, ayak A)
Civata M6x16 (Direk-travers sol, ayak A)
Cekic somun M6 (Direk-travers sol, ayak A)
Pul M6 (Direk-travers sol, ayak B)
Civata M6x16 (Direk-travers sol, ayak B)
Cekic somun M6 (Direk-travers sol, ayak B)
Ic kose baglanti kanal 10 (Sase sag arka on yuz)
Set vida M6x10 (Sase sag arka on yuz, ara ray)
Set vida M6x10 (Sase sag arka on yuz, uzun ray)
Ic kose baglanti kanal 10 (Sase sol arka on yuz)
Set vida M6x10 (Sase sol arka on yuz, ara ray)
Set vida M6x10 (Sase sol arka on yuz, uzun ray)
Ic kose baglanti kanal 10 (Sase sag orta on yuz)
Set vida M6x10 (Sase sag orta on yuz, ara ray)
Set vida M6x10 (Sase sag orta on yuz, uzun ray)
Ic kose baglanti kanal 10 (Sase sag orta arka yuz)
Set vida M6x10 (Sase sag orta arka yuz, ara ray)
Set vida M6x10 (Sase sag orta arka yuz, uzun ray)
Ic kose baglanti kanal 10 (Sase sol orta on yuz)
Set vida M6x10 (Sase sol orta on yuz, ara ray)
Set vida M6x10 (Sase sol orta on yuz, uzun ray)
Ic kose baglanti kanal 10 (Sase sol orta arka yuz)
Set vida M6x10 (Sase sol orta arka yuz, ara ray)
Set vida M6x10 (Sase sol orta arka yuz, uzun ray)
Ic kose baglanti kanal 10 (Sase sag on arka yuz)
Set vida M6x10 (Sase sag on arka yuz, ara ray)
Set vida M6x10 (Sase sag on arka yuz, uzun ray)
Ic kose baglanti kanal 10 (Sase sol on arka yuz)
Set vida M6x10 (Sase sol on arka yuz, ara ray)
Set vida M6x10 (Sase sol on arka yuz, uzun ray)
Omuz yuvasi (sag)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

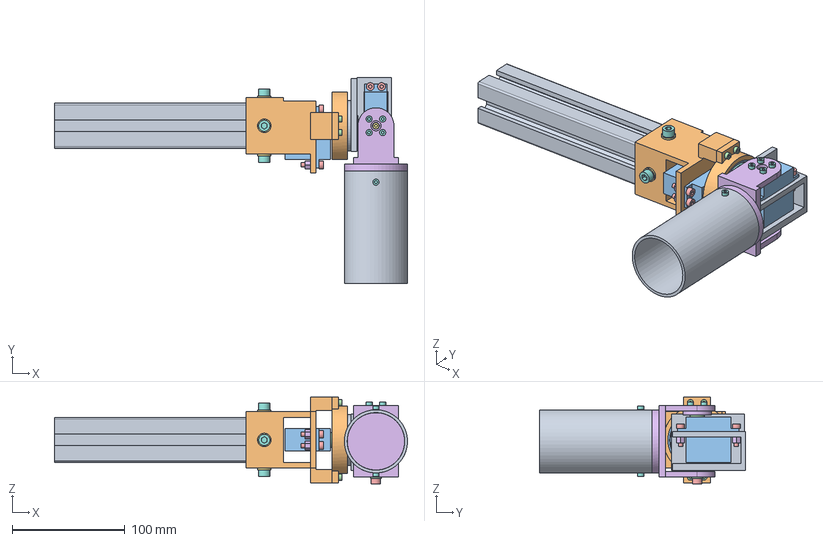
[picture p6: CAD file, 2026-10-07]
tasarim/freecad/omuz/omuz-montaj.step
313.0 x 183.0 x 77.0 mm

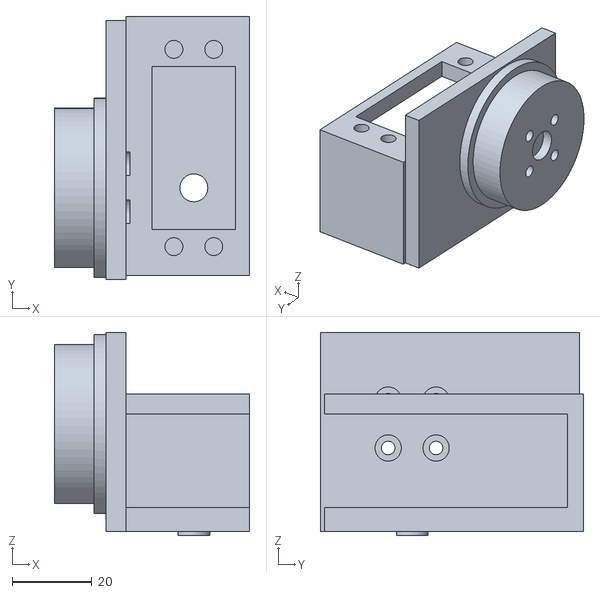
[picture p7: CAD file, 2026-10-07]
tasarim/freecad/omuz/stl/omuz-gobegi.stl
49.0 x 66.0 x 51.0

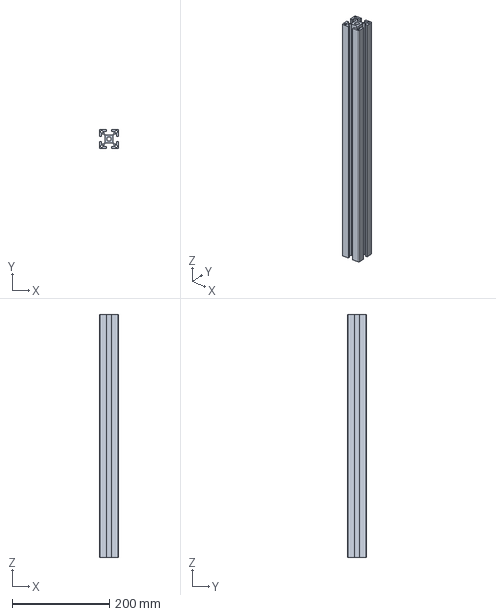
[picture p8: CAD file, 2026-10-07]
tasarim/freecad/sigma-test.step
40.0 x 40.0 x 500.0 mm

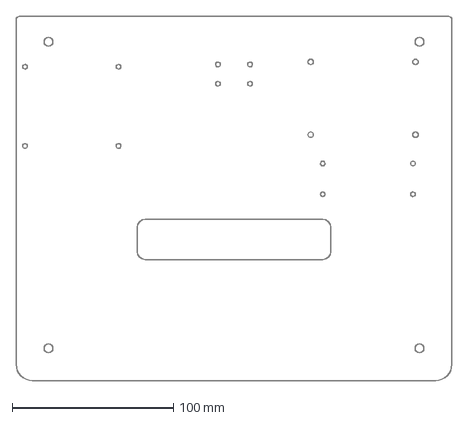
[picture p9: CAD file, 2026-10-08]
tasarim/freecad/taban/dxf/elektronik-kati-on-5mm-kontrplak.dxf
270.0 x 225.8 mm

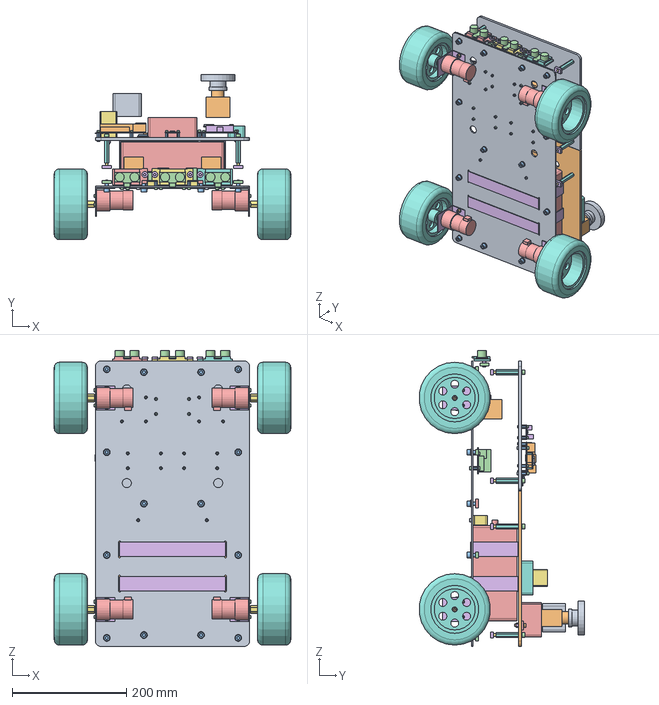
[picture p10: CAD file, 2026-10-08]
tasarim/freecad/taban/taban-montaj.step
414.0 x 289.5 x 518.0 mm

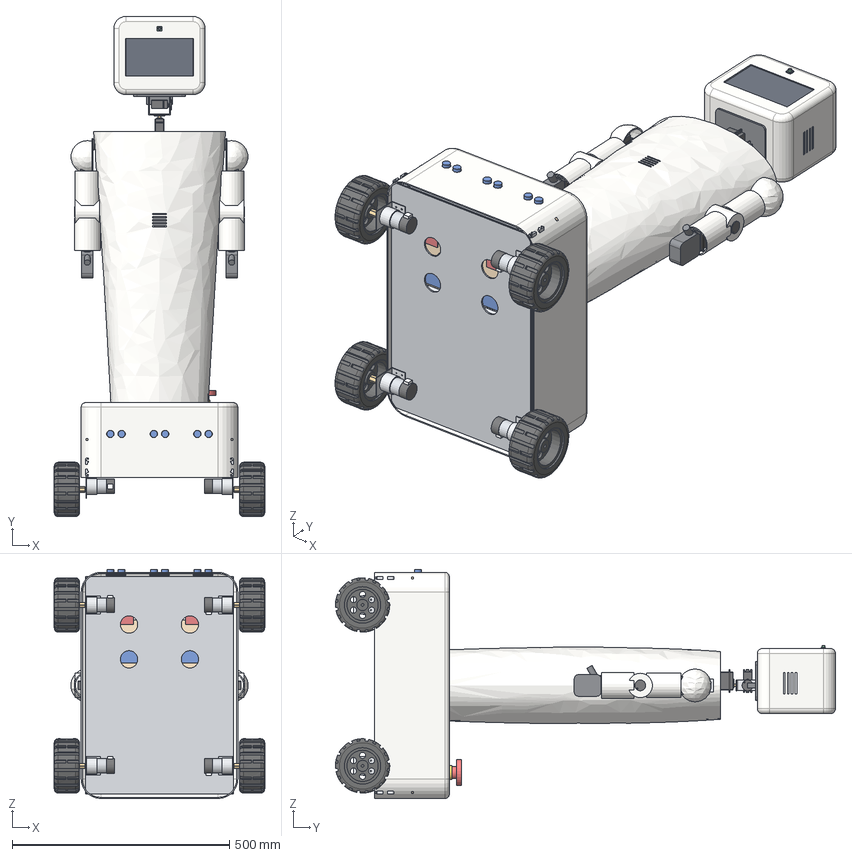
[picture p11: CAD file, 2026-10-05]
tasarim/cad/Humanoid-Robot-Montaj.step
484.0 x 1150.0 x 526.5 mm
Sase_uzun_rayi_1
Sase_uzun_rayi_2
Sase_ara_rayi_1
Sase_ara_rayi_2
Sase_ara_rayi_3
Alt_plaka__3_mm_aluminyum__lazer_kesim_1
Elektronik_kati__5_mm_kontrplak__lazer_kesim_1
M5_x_40_mesafe_burcu_1
M5_x_40_mesafe_burcu_2
M5_x_40_mesafe_burcu_3
M5_x_40_mesafe_burcu_4
JGB37_520_enkoderli_motor__60_dev_dk_1
JGB37_L_montaj_braketi_1
12_mm_altigen_kaplin__6_mm_mil_1
125_x_58_mm_arazi_tekerlegi_1
JGB37_520_enkoderli_motor__60_dev_dk_2
JGB37_L_montaj_braketi_2
12_mm_altigen_kaplin__6_mm_mil_2
125_x_58_mm_arazi_tekerlegi_2
JGB37_520_enkoderli_motor__60_dev_dk_3
JGB37_L_montaj_braketi_3
12_mm_altigen_kaplin__6_mm_mil_3
125_x_58_mm_arazi_tekerlegi_3
JGB37_520_enkoderli_motor__60_dev_dk_4
JGB37_L_montaj_braketi_4
12_mm_altigen_kaplin__6_mm_mil_4
125_x_58_mm_arazi_tekerlegi_4
LiFePO4_12_8_V_20_Ah_aku__yatik_1
BTS7960_43A_motor_surucu_1
BTS7960_43A_motor_surucu_2
XL4016_DC_DC_dusurucu_1
XL4016_DC_DC_dusurucu_2
XL4016_DC_DC_dusurucu_3
Raspberry_Pi_5_8GB___Active_Cooler_1
ESP32_WROOM_32D_DevKit_1
PCA9685_16_kanal_servo_surucu_1
BNO055_IMU_karti_1
MAX98357A_I2S_amfi_1
Taban_kapagi__PETG_3D_baski__4_parca_1
HC_SR04_ultrasonik_sensor_1
HC_SR04_ultrasonik_sensor_2
HC_SR04_ultrasonik_sensor_3
22_mm_mantar_acil_stop_butonu_1
Govde_diregi_1
40x40_genis_kose_baglanti_1
40x40_genis_kose_baglanti_2
Omuz_traversi_1
40x40_genis_kose_baglanti_3
40x40_genis_kose_baglanti_4
Govde_kabugu__PETG_3D_baski__6_parca_1
40_mm_3_W_hoparlor_1
DS3218MG_servo__20_kg_cm_1 x 3
Servo_kizagi__2_mm_aluminyum_1
DS3218MG_servo__20_kg_cm_2
Servo_kizagi__2_mm_aluminyum_2
Boyun_plakasi__3_mm_aluminyum_1
MG996R_servo___10_kg_cm_1 x 3
Kafa_egme_U_braketi__2_mm_Al_1
MG996R_servo___10_kg_cm_2 x 3
Kafa_tasiyici_plaka__PETG_1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

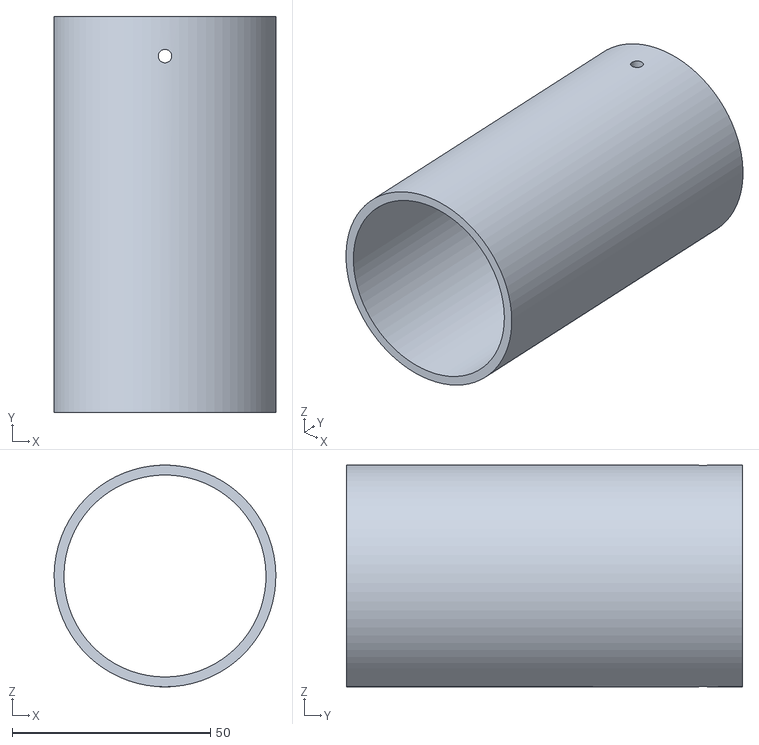
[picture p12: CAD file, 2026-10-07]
tasarim/freecad/omuz/stl/ust-kol-tupu.stl
56.0 x 100.0 x 56.0

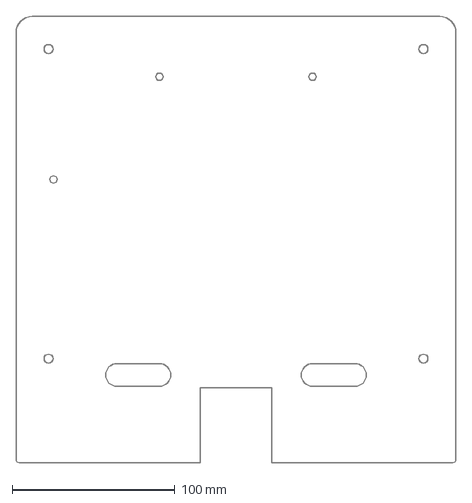
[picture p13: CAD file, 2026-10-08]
tasarim/freecad/taban/dxf/guc-paneli-arka-5mm-kontrplak.dxf
270.0 x 273.8 mm

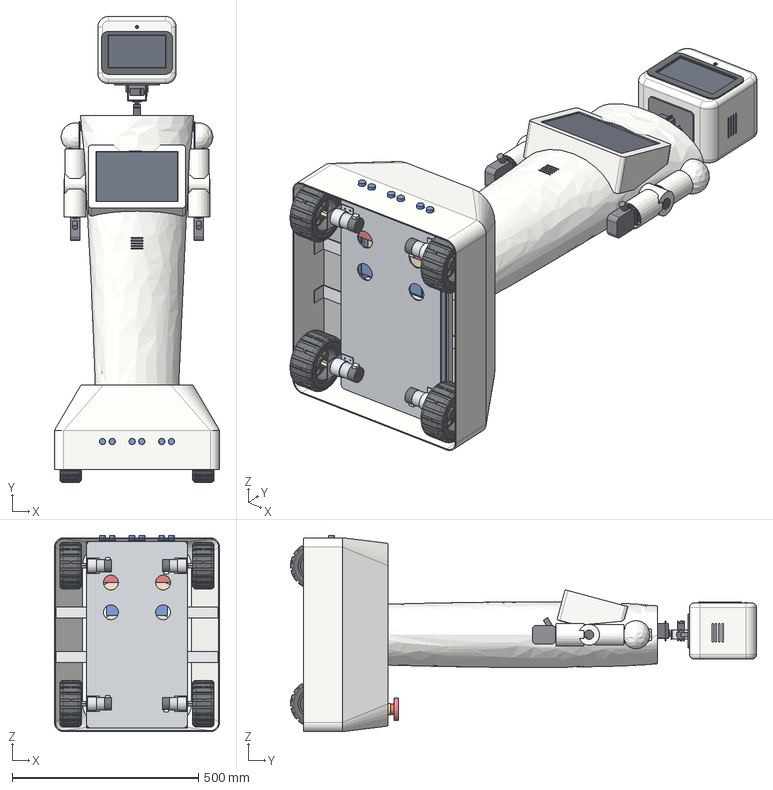
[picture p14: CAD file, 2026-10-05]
tasarim/cad/Humanoid-Robot-Montaj-V3.step
443.0 x 1250.0 x 526.5 mm
Sase_uzun_rayi_1
Sase_uzun_rayi_2
Sase_ara_rayi_1
Sase_ara_rayi_2
Sase_ara_rayi_3
Alt_plaka_V3__3_mm_aluminyum__lazer_kesim_1
Elektronik_kati_V3__5_mm_kontrplak__lazer_kesim_1
M5_x_40_mesafe_burcu_1
M5_x_40_mesafe_burcu_2
M5_x_40_mesafe_burcu_3
M5_x_40_mesafe_burcu_4
JGB37_520_enkoderli_motor__60_dev_dk_1
JGB37_L_montaj_braketi_1
12_mm_altigen_kaplin__6_mm_mil_1
125_x_58_mm_arazi_tekerlegi_1
JGB37_520_enkoderli_motor__60_dev_dk_2
JGB37_L_montaj_braketi_2
12_mm_altigen_kaplin__6_mm_mil_2
125_x_58_mm_arazi_tekerlegi_2
JGB37_520_enkoderli_motor__60_dev_dk_3
JGB37_L_montaj_braketi_3
12_mm_altigen_kaplin__6_mm_mil_3
125_x_58_mm_arazi_tekerlegi_3
JGB37_520_enkoderli_motor__60_dev_dk_4
JGB37_L_montaj_braketi_4
12_mm_altigen_kaplin__6_mm_mil_4
125_x_58_mm_arazi_tekerlegi_4
LiFePO4_12_8_V_20_Ah_aku__yatik_1
BTS7960_43A_motor_surucu_1
BTS7960_43A_motor_surucu_2
XL4016_DC_DC_dusurucu_1
XL4016_DC_DC_dusurucu_2
XL4016_DC_DC_dusurucu_3
Raspberry_Pi_5_8GB___Active_Cooler_1
ESP32_WROOM_32D_DevKit_1
PCA9685_16_kanal_servo_surucu_1
BNO055_IMU_karti_1
MAX98357A_I2S_amfi_1
HC_SR04_ultrasonik_sensor_1
HC_SR04_ultrasonik_sensor_2
HC_SR04_ultrasonik_sensor_3
Taban_etegi_V3__tekerlekleri_sarar__yukari_daral_1
Etek_tasiyici_L_braket__2_mm_Al_1
Etek_tasiyici_L_braket__2_mm_Al_2
Etek_tasiyici_L_braket__2_mm_Al_3
Etek_tasiyici_L_braket__2_mm_Al_4
22_mm_mantar_acil_stop_butonu_1
Govde_diregi_1
40x40_genis_kose_baglanti_1
40x40_genis_kose_baglanti_2
Omuz_traversi_1
40x40_genis_kose_baglanti_3
40x40_genis_kose_baglanti_4
Govde_kabugu_V3__egik_gogus_ekrani___PETG_3D_bas_1
10_1__HDMI_LCD__gogus_ekrani_1
40_mm_3_W_hoparlor_1
DS3218MG_servo__20_kg_cm_1 x 3
Servo_kizagi__2_mm_aluminyum_1
DS3218MG_servo__20_kg_cm_2
Servo_kizagi__2_mm_aluminyum_2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

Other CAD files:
tasarim/freecad/omuz/stl/kol-catali.stl
tasarim/freecad/taban/dxf/alt-plaka-3mm-al.dxf
tasarim/freecad/omuz/stl/rulman-kapagi.stl
tasarim/freecad/omuz/stl/omuz-yuvasi.stl
tasarim/cad/Humanoid-Robot-Montaj-V2.step
tasarim/freecad/dirsek/dirsek-montaj.FCStd
tasarim/freecad/iskelet/iskelet-montaj.FCStd
tasarim/freecad/kabuk/kabuk-montaj.FCStd
tasarim/freecad/kafa/kafa-montaj.FCStd
tasarim/freecad/montaj/robot-montaj.FCStd
tasarim/freecad/omuz/omuz-montaj.FCStd
tasarim/freecad/sigma-test.FCStd
tasarim/freecad/taban/taban-montaj.FCStd

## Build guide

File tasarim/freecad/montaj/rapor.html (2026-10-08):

# Robot ana montajı: tam robot (iskelet, omuzlar, kabuk, dirsekler, kafa, taban)

FreeCAD 1.1 Assembly · ana_montaj.py · 907 parça, 22 grup, 22 eklem · yerleşim arayuz.MODULLER'den · sol omuz ve sol dirsek gerçek aynalı geometri

907parça (iskelet 59 + 2 x (omuz 70 - travers - kabuk referansi) + kabuk 202 + dirsek_sag 53 + dirsek_sol 53 + kafa 98 + taban 306) · tümü geçerli, STEP geri okuma 907 katı

21,26 kgkütle · AM (-0,4; 375; -13,5) mm · modül toplamından fark -0,01 g

1206eklem aralığında modüller arası çakışma (ev pozu + 600706 poz tarama; aralık dışı 384)

14 eksen2 kol × (öne-arka, yana açma, dirsek, bilek) + kafa (pan, tilt) + 4 teker (sınırsız) · iskelet zemine sabit, omuzlar, kabuk, kafanın boynu ve taban iskelete, dirsekler omuz koluna sabit

21,66 kgkablo payı (400 g, tahmini) dahil · taban raporundaki 21,66 kg ile fark 0,0 g, AM farkı 0,03 mm

2,3·10⁻¹⁰ mmeklem doğrulama en büyük sapma (66 poz, 3432 çözücü karesi) · açı 4,9e-11°

doğrulandıGUI'de açılış: eklemler görünür, ağaçta ve 3B'de seçilebilir, sürükleme çalışıyor

## Görünümler

İzometrik: tam robot (iskelet, iki omuz, kabuk, iki dirsek, kafa, taban)

İzometrik: tam robot (iskelet, iki omuz, kabuk, iki dirsek, kafa, taban)

Önden (+Z'den bakış; robotun sağı görüntünün solunda)

Önden (+Z'den bakış; robotun sağı görüntünün solunda)

Yandan (+X'ten bakış)

Yandan (+X'ten bakış)

Omuzlar yakından: sol omuz sağın aynası

Omuzlar yakından: sol omuz sağın aynası

Sağ dirsek ev pozunda: kol aşağıda, çatal kabuğun yanında

Sağ dirsek ev pozunda: kol aşağıda, çatal kabuğun yanında

Kafa ev pozunda: boyun kabuk üst kapağının R62 halkasından çıkıyor

Kafa ev pozunda: boyun kabuk üst kapağının R62 halkasından çıkıyor

Taban arkadan: etek, acil stop mantarı, tekerler

Taban arkadan: etek, acil stop mantarı, tekerler

Taban, etek gizli: akü, güç paneli, elektronik katı, motorlar, sonarlar

Taban, etek gizli: akü, güç paneli, elektronik katı, motorlar, sonarlar

Poz: sağ kol yana 100°, öne 20°, dirsek 95°, bilek −60°; sol kol yana 10°, dirsek 30°; kafa pan 30°, tilt −10°

Poz: sağ kol yana 100°, öne 20°, dirsek 95°, bilek −60°; sol kol yana 10°, dirsek 30°; kafa pan 30°, tilt −10°

Poz: iki kol öne 90°, dirsek 60°, bilek 45°; kafa tilt 25° (ellere bakar)

Poz: iki kol öne 90°, dirsek 60°, bilek 45°; kafa tilt 25° (ellere bakar)

Poz: kafa pan 45°, tilt 20°; sağ kol öne 45°, yana 20°, dirsek 60°

Poz: kafa pan 45°, tilt 20°; sağ kol öne 45°, yana 20°, dirsek 60°

İki kol ve kafa birlikte (Kollari_oynat simülasyonu, FreeCAD çözücüsünün kareleri): omuzlar zıt fazda öne-arka sallanır, birlikte öne kalkıp yana açılır; sağ dirsek iki kez, sol dirsek bir kez bükülür, bilekler zıt yönde döner; kafa ±46° sağa sola bakar, ±14° başını eğip kaldırır; tekerler 8 s'de 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

İki kol ve kafa birlikte (Kollari_oynat simülasyonu, FreeCAD çözücüsünün kareleri): omuzlar zıt fazda öne-arka sallanır, birlikte öne kalkıp yana açılır; sağ dirsek iki kez, sol dirsek bir kez bükülür, bilekler zıt yönde döner; kafa ±46° sağa sola bakar, ±14° başını eğip kaldırır; tekerler 8 s'de bir tur ileri döner

## Modüller

Modül | Parça | Kütle | Ağırlık merkezi (mm) | Yerel orijin (global) | Dönüş | Ana montajda yok | Gruplar
İskelet | 59 | 5.793,1 g | (0,0; 314,5; 0,0) | (0; 0; 0) | – | – | iskelet
Sağ omuz | 68 (modülde 70) | 463,6 g | (150,9; 943,9; -0,8) | (0; 955; 0) | – | Omuz traversi (sigma 40x40 agir, 200 mm), Govde kabugu yan yuzu (referans) | sağ omuz gövde, sağ omuz göbeği, sağ üst kol
Sol omuz | 68 (modülde 70) | 463,6 g | (-150,9; 943,9; -0,8) | (0; 955; 0) | X aynası (gerçek aynalı geometri) | Omuz traversi (sigma 40x40 agir, 200 mm), Govde kabugu yan yuzu (referans) | sol omuz gövde, sol omuz göbeği, sol üst kol
Kabuk | 202 | 4.925,9 g | (-0,1; 467,2; 8,5) | (0; 0; 0) | – | – | kabuk
Sağ dirsek | 53 | 370,0 g | (189,3; 748,7; -1,6) | (0; 955; 0) | – | – | sağ dirsek çatalı, sağ ön kol, sağ el
Sol dirsek | 53 | 370,0 g | (-189,3; 748,7; -1,6) | (0; 955; 0) | X aynası (gerçek aynalı geometri) | – | sol dirsek çatalı, sol ön kol, sol el
Kafa | 98 (modülde 99) | 1.366,8 g | (0,6; 1.108,5; 21,1) | (0; 975; 0) | – | Kablo demeti (gosterim) | kafa gövdesi (boyun), kafa pan grubu, kafa

Taban

306 (modülde 319)

7.508,0 g

(-1,1; 119,5; -47,4)

(0; 0; 0)

–

Ana anahtar dugmesi (gosterim, kabuk deligi gerekir), Kablo yolu 1: 12 V ana hat: aku + -> XT60 -> ana sigorta 30 A -> ana anahtar -> sigorta kutusu, Kablo yolu 2: Toprak: aku - -> WAGO yildiz noktasi (guc paneli) -> tum donusturuculer, Kablo yolu 3: Motor 12 V: F1 20 A -> role -> WAGO -> BTS7960 sol/sag -> motor kablo delikleri -> 4 motor, Kablo yolu 4: Motor 12 V sag kol + arka motorlar (plaka altindan z 36 deliginden), Kablo yolu 5: Servo 6 V: F1 -> role -> WAGO -> XL4016 servo -> PCA9685 V+ -> direk arka yuzu -> omuz / kafa, Kablo yolu 6: Servo kablolari sola ve kafaya (direk ustu dagitim), Kablo yolu 7: Pi 5,1 V: F3 10 A -> XL4016 Pi -> Pi USB-C, Kablo yolu 8: Cevre 5 V: F4 5 A -> XL4016 cevre -> ESP32 / Nextion / 7in LCD / sensorler, Kablo yolu 9: Acil stop: F5 -> mantar (NC) -> role bobini, Kablo yolu 10: Sinyal: sonar x3 -> ESP32 (on ara ray ustunden), Kablo yolu 11: Sinyal: enkoder + BTS PWM/EN -> ESP32; Pi <-> ESP32 USB, Kablo yolu 12: Pi -> kafa: 2x HDMI (7in LCD), kamera FPC, USB mikrofon, hoparlor (direk on yuzu)

taban gövdesi, ön sağ teker, ön sol teker, arka sağ teker, arka sol teker
Toplam | 907 | 21.260,9 g | (-0,4; 374,6; -13,5) | | | | 22 grup

Kütle ve AM dosyadan geri okunarak hesaplandı (her parçanın Kutle_g özelliği ve katı kütle merkezi). Modül analizlerinin toplamı (iskelet + 2 × omuz, travers hariç + kabuk + 2 × dirsek + kafa + taban) = 21.260,9 g, carpisma.py = 21.260,9 g; fark -0,014 g (analiz JSON'ları 0,1 g'a yuvarlı). AM, carpisma.py sonucundan 0,007 mm farklı (yuvarlama). Parça sayısı 907 = iskelet 59 + 2 x (omuz 70 - travers - kabuk referansi) + kabuk 202 + dirsek_sag 53 + dirsek_sol 53 + kafa 98 + taban 306.

## Eklemler

Eklem | Tip | Bağladığı | Konum ve eksen (global, mm) | Sınır | Doğrulama sapması (kolun tüm pozlarında en büyük) | Sürükleme (GUI, yol boyunca)
Iskelet zemine sabit | Zemine sabit | iskelet | – | – | – | –
OmuzSag Govde -> iskelet (sabit) | Sabit (Fixed) | iskelet → sağ omuz gövde | (86,5; 955,0; 0,0) | – | – | omuz yuvasi travers ucunda, 4x M6 + cekic somun (arayuz.OMUZ_YUVA_X)
Sağ öne-arka (S1) | Döner (Revolute) | sağ omuz gövde → sağ omuz göbeği | (150,0; 955,0; 0,0) · yön (-1; 0; 0) | -45° … 135° | 2,3·10⁻¹⁰ mm · 4,9·10⁻¹¹° (28 poz) | -43° … 98° arası sürüklendi
Sağ yana açma (S2) | Döner (Revolute) | sağ omuz göbeği → sağ üst kol | (185,0; 955,0; 20,2) · yön (0; 0; 1) | 0° … 120° | 2,3·10⁻¹⁰ mm · 4,9·10⁻¹¹° (28 poz) | 0° … 120° arası sürüklendi
OmuzSol Govde -> iskelet (sabit) | Sabit (Fixed) | iskelet → sol omuz gövde | (-86,5; 955,0; 0,0) | – | – | omuz yuvasi travers ucunda, 4x M6 + cekic somun (arayuz.OMUZ_YUVA_X)
Sol öne-arka (S1) | Döner (Revolute) | sol omuz gövde → sol omuz göbeği | (-150,0; 955,0; 0,0) · yön (-1; 0; 0) | -45° … 135° | 2,3·10⁻¹⁰ mm · 4,9·10⁻¹¹° (28 poz) | -43° … 0° arası sürüklendi
Sol yana açma (S2) | Döner (Revolute) | sol omuz göbeği → sol üst kol | (-185,0; 955,0; 20,2) · yön (0; 0; -1) | 0° … 120° | 2,3·10⁻¹⁰ mm · 4,9·10⁻¹¹° (28 poz) | 0° … 34° arası sürüklendi
Kabuk Kabuk -> iskelet (sabit) | Sabit (Fixed) | iskelet → kabuk | (0,0; 600,0; 0,0) | – | – | govde braketleri direk yan kanallarina (4 braket x 2 M6), etek braketleri uzun ray ust kanallarina (6 x M6), cekic somunla (arayuz.KABUK_GOVDE_BRAKET / KABUK_ETEK_BRAKET)
DirsekSag UstKol -> omuz_sag (sabit) | Sabit (Fixed) | sağ üst kol → sağ dirsek çatalı | (185,0; 815,0; -1,2) | – | – | dirsek catali ust kol tupunun ucuna: pim + yarikli sikma bilezigi, 2x M3 (arayuz.DIRSEK)
Sağ dirsek | Döner (Revolute) | sağ dirsek çatalı → sağ ön kol | (216,6; 782,0; -1,2) · yön (-1; 0; 0) | 0° … 105° | 2,3·10⁻¹⁰ mm · 4,9·10⁻¹¹° (16 poz) | 0° … 105° arası sürüklendi
Sağ bilek | Döner (Revolute) | sağ ön kol → sağ el | (185,0; 698,9; -1,2) · yön (0; 1; 0) | -90° … 90° | 2,3·10⁻¹⁰ mm · 4,9·10⁻¹¹° (16 poz) | –
DirsekSol UstKol -> omuz_sol (sabit) | Sabit (Fixed) | sol üst kol → sol dirsek çatalı | (-185,0; 815,0; -1,2) | – | – | dirsek catali ust kol tupunun ucuna: pim + yarikli sikma bilezigi, 2x M3 (arayuz.DIRSEK)
Sol dirsek | Döner (Revolute) | sol dirsek çatalı → sol ön kol | (-216,6; 782,0; -1,2) · yön (-1; 0; 0) | 0° … 105° | 2,3·10⁻¹⁰ mm · 4,9·10⁻¹¹° (16 poz) | –
Sol bilek | Döner (Revolute) | sol ön kol → sol el | (-185,0; 698,9; -1,2) · yön (0; -1; 0) | -90° … 90° | 2,3·10⁻¹⁰ mm · 4,9·10⁻¹¹° (16 poz) | –
Kafa Govde -> iskelet (sabit) | Sabit (Fixed) | iskelet → kafa gövdesi (boyun) | (0,0; 975,0; 0,0) | – | – | boyun plakasi traversin ust kanalina 2x M6 + cekic somun (x = +-40, z = 0; arayuz.KAFA boyun_plaka)
Kafa pan | Döner (Revolute) | kafa gövdesi (boyun) → kafa pan grubu | (0,0; 1.019,6; 0,0) · yön (0; 1; 0) | -90° … 90° | 2,3·10⁻¹⁰ mm · 4,9·10⁻¹¹° (15 poz) | -14° … 3° arası sürüklendi
Kafa tilt | Döner (Revolute) | kafa pan grubu → kafa | (26,9; 1.105,0; 25,0) · yön (1; 0; 0) | -25° … 30° | 2,3·10⁻¹⁰ mm · 4,9·10⁻¹¹° (15 poz) | 0° … 30° arası sürüklendi
Taban Govde -> iskelet (sabit) | Sabit (Fixed) | iskelet → taban gövdesi | (0,0; 94,5; 0,0) | – | – | alt plaka uzun ve ara raylarin alt kanallarina 14x M6 + cekic somun (arayuz.TABAN plaka_ray_z / plaka_ara_x); motor braketleri plaka uzerinden uzun raylara M4 + cekic somun
Taban ön sağ teker | Döner (Revolute) | taban gövdesi → ön sağ teker | (178,0; 62,5; 185,0) · yön (1; 0; 0) | sınırsız (serbest dönüş) | 1,1·10⁻¹⁰ mm · 4,3·10⁻¹¹° (8 poz) | –
Taban ön sol teker | Döner (Revolute) | taban gövdesi → ön sol teker | (-178,0; 62,5; 185,0) · yön (1; 0; 0) | sınırsız (serbest dönüş) | 1,1·10⁻¹⁰ mm · 4,3·10⁻¹¹° (8 poz) | –
Taban arka sağ teker | Döner (Revolute) | taban gövdesi → arka sağ teker | (178,0; 62,5; -185,0) · yön (1; 0; 0) | sınırsız (serbest dönüş) | 1,1·10⁻¹⁰ mm · 4,3·10⁻¹¹° (8 poz) | –
Taban arka sol teker | Döner (Revolute) | taban gövdesi → arka sol teker | (-178,0; 62,5; -185,0) · yön (1; 0; 0) | sınırsız (serbest dönüş) | 1,1·10⁻¹⁰ mm · 4,3·10⁻¹¹° (8 poz) | –

Pozitif açı: öne-arka = kol öne (+Z) kalkar, yana açma = kol dışarı açılır (sağda +X, solda −X). Çözücü sonrası kol ucu kontrolü: öne +90° → (±185; 955; 140), yana +90° → (±325; 955; 0); kafa pan +90° → kamera robotun sağına (+X), tilt +30° → yüz aşağı; teker +90° → tekerin alt noktası 62,5 mm geri (−Z) ve aks yüksekliğine (ileri yuvarlanma); hepsi doğru.

## Eklem doğrulaması

Yöntem: FreeCAD 1.1'de Revolute açısı doğrudan sürülemiyor (Angle yalnız Angle ekleminde). Eklemler Create Simulation'ın kullandığı yolla sürüldü: her döner ekleme bir hareket (Motion, Angular, formül = açı × time), 0…1 s, 0,02 s adım. Her karede çözücünün verdiği grup yerleşimi, modülün kendi kinematiğiyle (omuz_parcalar.Pp/Pr, dirsek_parcalar ve kafa_parcalar.grup_yer, solda X aynasıyla T·R·P·R·T⁻¹) karşılaştırıldı. Sapma: grubun sınır kutusu köşelerindeki en büyük konum farkı ve dönüş farkı. Birim testi: formül 1 rad → 57,296° (formül radyan).

Sonuç: sınır içindeki 66 pozun (omuz sağ/sol 10'ar, omuz + dirsek + bilek sağ/sol 10'ar, iki kol birlikte 4, kafa pan × tilt 11, kafa + iki kol 3, teker 8) tüm karelerinde en büyük sapma 2,3·10⁻¹⁰ mm ve 4,9·10⁻¹¹°; sürülmeyen gruplar (iskelet, omuz gövdeleri, kabuk, kafanın boynu, taban gövdesi, diğer kol) yerinde kaldı, dirsek grupları omuzla birlikte doğru taşındı. Eksenler ve sol aynalama doğru.

Sürülen poz | Kare | Konum sapması mm | Dönüş sapması ° | Açı hatası °
sağ öne 30° yana 0° | 52 | 9,8·10⁻¹¹ | 1,7·10⁻¹¹ | 1,7·10⁻¹¹
sağ öne 90° yana 0° | 52 | 3,4·10⁻¹¹ | 6,0·10⁻¹² | 6,0·10⁻¹²
sağ öne 135° yana 0° | 52 | 1,1·10⁻¹⁰ | 2,0·10⁻¹¹ | 2,0·10⁻¹¹
sağ öne -45° yana 0° | 52 | 1,5·10⁻¹⁰ | 2,6·10⁻¹¹ | 2,6·10⁻¹¹
sağ öne 0° yana 60° | 52 | 1,3·10⁻¹⁰ | 2,3·10⁻¹¹ | 2,3·10⁻¹¹
sağ öne 0° yana 120° | 52 | 6,3·10⁻¹¹ | 1,1·10⁻¹¹ | 1,1·10⁻¹¹
sağ öne 90° yana 90° | 52 | 3,7·10⁻¹¹ | 8,4·10⁻¹² | 6,0·10⁻¹²
sağ öne -30° yana 45° | 52 | 1,7·10⁻¹⁰ | 3,1·10⁻¹¹ | 2,6·10⁻¹¹
sağ öne 60° yana 30° | 52 | 1,6·10⁻¹⁰ | 2,9·10⁻¹¹ | 2,3·10⁻¹¹
sağ öne 135° yana 120° | 52 | 9,6·10⁻¹¹ | 2,3·10⁻¹¹ | 2,0·10⁻¹¹
sol öne 30° yana 0° | 52 | 9,8·10⁻¹¹ | 1,7·10⁻¹¹ | 1,7·10⁻¹¹
sol öne 90° yana 0° | 52 | 3,4·10⁻¹¹ | 6,0·10⁻¹² | 6,0·10⁻¹²
sol öne 135° yana 0° | 52 | 1,1·10⁻¹⁰ | 2,0·10⁻¹¹ | 2,0·10⁻¹¹
sol öne -45° yana 0° | 52 | 1,5·10⁻¹⁰ | 2,6·10⁻¹¹ | 2,6·10⁻¹¹
sol öne 0° yana 60° | 52 | 1,3·10⁻¹⁰ | 2,3·10⁻¹¹ | 2,3·10⁻¹¹
sol öne 0° yana 120° | 52 | 6,4·10⁻¹¹ | 1,1·10⁻¹¹ | 1,1·10⁻¹¹
sol öne 90° yana 90° | 52 | 3,7·10⁻¹¹ | 8,4·10⁻¹² | 6,0·10⁻¹²
sol öne -30° yana 45° | 52 | 1,7·10⁻¹⁰ | 3,1·10⁻¹¹ | 2,6·10⁻¹¹
sol öne 60° yana 30° | 52 | 1,6·10⁻¹⁰ | 2,9·10⁻¹¹ | 2,3·10⁻¹¹
sol öne 135° yana 120° | 52 | 9,6·10⁻¹¹ | 2,3·10⁻¹¹ | 2,0·10⁻¹¹
sağ öne 0° yana 0° dirsek 30° bilek 0° | 52 | 4,7·10⁻¹¹ | 1,7·10⁻¹¹ | 1,7·10⁻¹¹
sağ öne 0° yana 0° dirsek 60° bilek 45° | 52 | 7,8·10⁻¹¹ | 3,5·10⁻¹¹ | 2,6·10⁻¹¹
sağ öne 0° yana 0° dirsek 105° bilek -90° | 52 | 2,0·10⁻¹¹ | 6,3·10⁻¹² | 5,9·10⁻¹²
sağ öne 0° yana 0° dirsek 90° bilek 90° | 52 | 2,5·10⁻¹¹ | 8,3·10⁻¹² | 6,0·10⁻¹²
sağ öne 90° yana 0° dirsek 90° bilek 45° | 52 | 5,1·10⁻¹¹ | 2,8·10⁻¹¹ | 2,6·10⁻¹¹
sağ öne 45° yana 60° dirsek 60° bilek -45° | 52 | 1,1·10⁻¹⁰ | 3,5·10⁻¹¹ | 2,6·10⁻¹¹
sağ öne 135° yana 120° dirsek 105° bilek 90° | 52 | 8,6·10⁻¹¹ | 2,6·10⁻¹¹ | 2,0·10⁻¹¹
sağ öne -45° yana 30° dirsek 0° bilek -90° | 52 | 1,6·10⁻¹⁰ | 3,1·10⁻¹¹ | 2,6·10⁻¹¹
sağ öne 60° yana 30° dirsek 45° bilek 30° | 52 | 9,7·10⁻¹¹ | 2,9·10⁻¹¹ | 2,6·10⁻¹¹
sağ öne 90° yana 90° dirsek 105° bilek -60° | 52 | 4,6·10⁻¹¹ | 3,1·10⁻¹¹ | 2,3·10⁻¹¹
sol öne 0° yana 0° dirsek 30° bilek 0° | 52 | 4,7·10⁻¹¹ | 1,7·10⁻¹¹ | 1,7·10⁻¹¹
sol öne 0° yana 0° dirsek 60° bilek 45° | 52 | 7,8·10⁻¹¹ | 3,5·10⁻¹¹ | 2,6·10⁻¹¹
sol öne 0° yana 0° dirsek 105° bilek -90° | 52 | 2,0·10⁻¹¹ | 6,4·10⁻¹² | 5,9·10⁻¹²
sol öne 0° yana 0° dirsek 90° bilek 90° | 52 | 2,5·10⁻¹¹ | 8,3·10⁻¹² | 6,0·10⁻¹²
sol öne 90° yana 0° dirsek 90° bilek 45° | 52 | 5,1·10⁻¹¹ | 2,8·10⁻¹¹ | 2,6·10⁻¹¹
sol öne 45° yana 60° dirsek 60° bilek -45° | 52 | 1,1·10⁻¹⁰ | 3,5·10⁻¹¹ | 2,6·10⁻¹¹
sol öne 135° yana 120° dirsek 105° bilek 90° | 52 | 8,5·10⁻¹¹ | 2,6·10⁻¹¹ | 2,0·10⁻¹¹
sol öne -45° yana 30° dirsek 0° bilek -90° | 52 | 1,6·10⁻¹⁰ | 3,1·10⁻¹¹ | 2,6·10⁻¹¹
sol öne 60° yana 30° dirsek 45° bilek 30° | 52 | 9,7·10⁻¹¹ | 2,9·10⁻¹¹ | 2,6·10⁻¹¹
sol öne 90° yana 90° dirsek 105° bilek -60° | 52 | 4,6·10⁻¹¹ | 3,1·10⁻¹¹ | 2,3·10⁻¹¹
sağ öne 90° yana 45°; sol öne 90° yana 45° | 52 | 1,5·10⁻¹⁰ | 2,6·10⁻¹¹ | 2,6·10⁻¹¹
sağ öne 120° yana 30°; sol öne -30° yana 90° | 52 | 1,2·10⁻¹⁰ | 2,0·10⁻¹¹ | 1,7·10⁻¹¹
sağ öne 90° yana 0° dirsek 60° bilek 45°; sol öne 90° yana 0° dirsek 60° bilek -45° | 52 | 1,0·10⁻¹⁰ | 3,9·10⁻¹¹ | 2,6·10⁻¹¹
sağ öne 30° yana 20° dirsek 105° bilek 90°; sol öne -30° yana 40° dirsek 30° bilek -90° | 52 | 1,0·10⁻¹⁰ | 2,3·10⁻¹¹ | 1,7·10⁻¹¹
kafa pan 30° tilt 0° | 52 | 4,2·10⁻¹¹ | 1,7·10⁻¹¹ | 1,7·10⁻¹¹
kafa pan 90° tilt 0° | 52 | 1,4·10⁻¹¹ | 5,9·10⁻¹² | 5,9·10⁻¹²
kafa pan -90° tilt 0° | 52 | 1,4·10⁻¹¹ | 5,8·10⁻¹² | 5,9·10⁻¹²
kafa pan -45° tilt 0° | 52 | 6,2·10⁻¹¹ | 2,6·10⁻¹¹ | 2,6·10⁻¹¹
kafa pan 0° tilt 30° | 52 | 5,2·10⁻¹¹ | 1,7·10⁻¹¹ | 1,7·10⁻¹¹
kafa pan 0° tilt -25° | 52 | 7,2·10⁻¹¹ | 2,4·10⁻¹¹ | 2,4·10⁻¹¹
kafa pan 60° tilt 20° | 52 | 8,2·10⁻¹¹ | 2,4·10⁻¹¹ | 2,3·10⁻¹¹
kafa pan -75° tilt -15° | 52 | 5,5·10⁻¹¹ | 1,7·10⁻¹¹ | 1,5·10⁻¹¹
kafa pan 90° tilt 30° | 52 | 6,3·10⁻¹¹ | 1,8·10⁻¹¹ | 1,7·10⁻¹¹
kafa pan -90° tilt -25° | 52 | 8,0·10⁻¹¹ | 2,5·10⁻¹¹ | 2,4·10⁻¹¹
kafa pan 45° tilt -10° | 52 | 1,2·10⁻¹⁰ | 3,6·10⁻¹¹ | 2,6·10⁻¹¹
sağ öne 20° yana 100° dirsek 95° bilek -60°; sol öne 10° yana 10° dirsek 30° bilek 0°; kafa pan 30° tilt -10° | 52 | 2,3·10⁻¹⁰ | 4,9·10⁻¹¹ | 2,5·10⁻¹¹
sağ öne 90° yana 0° dirsek 60° bilek 45°; sol öne 90° yana 0° dirsek 60° bilek -45°; kafa pan -60° tilt 20° | 52 | 1,0·10⁻¹⁰ | 3,9·10⁻¹¹ | 2,6·10⁻¹¹
sağ öne 45° yana 60° dirsek 60° bilek -45°; sol öne -30° yana 30° dirsek 0° bilek 0°; kafa pan 75° tilt 25° | 52 | 1,3·10⁻¹⁰ | 3,5·10⁻¹¹ | 2,6·10⁻¹¹
teker ön sağ 90° ön sol 0° arka sağ 0° arka sol 0° | 52 | 1,0·10⁻¹¹ | 6,0·10⁻¹² | 6,0·10⁻¹²
teker ön sağ 0° ön sol -45° arka sağ 0° arka sol 0° | 52 | 4,3·10⁻¹¹ | 2,6·10⁻¹¹ | 2,6·10⁻¹¹
teker ön sağ 0° ön sol 0° arka sağ 180° arka sol 0° | 52 | 2,1·10⁻¹¹ | 1,2·10⁻¹¹ | 1,2·10⁻¹¹
teker ön sağ 0° ön sol 0° arka sağ 0° arka sol -120° | 52 | 1,9·10⁻¹¹ | 1,1·10⁻¹¹ | 1,1·10⁻¹¹
teker ön sağ 30° ön sol 30° arka sağ 30° arka sol 30° | 52 | 2,9·10⁻¹¹ | 1,7·10⁻¹¹ | 1,7·10⁻¹¹
teker ön sağ -75° ön sol 75° arka sağ -75° arka sol 75° | 52 | 2,4·10⁻¹¹ | 1,5·10⁻¹¹ | 1,5·10⁻¹¹
teker ön sağ 400° ön sol -200° arka sağ 135° arka sol -720° | 52 | 3,3·10⁻¹¹ | 2,0·10⁻¹¹ | 2,0·10⁻¹¹
sağ öne 90° yana 0° dirsek 60° bilek 45°; sol öne -30° yana 30° dirsek 30° bilek -45°; kafa pan 30° tilt 10°; teker ön sağ 60° ön sol 60° arka sağ 60° arka sol 60° | 52 | 1,1·10⁻¹⁰ | 4,3·10⁻¹¹ | 2,6·10⁻¹¹

### Sınır dışına sürülünce

Simülasyon sınırları uygulamıyor: komut edilen açı aynen izleniyor. solve() da (GUI'de Solve, doc.recompute()) elle verilen sınır dışı pozu geri çekmiyor. Sınırlar yalnız fareyle sürüklemede durduruyor (aşağıdaki GUI tablosu).

Simülasyonla sürülen | Ölçülen açı | Konum sapması mm | Davranış
sağ öne 160° yana 0° | 160,0° | 2,3·10⁻¹¹ | sınır uygulanmadı, komut aynen izlendi
sağ öne 180° yana 0° | 180,0° | 6,6·10⁻¹¹ | sınır uygulanmadı, komut aynen izlendi
sağ öne -60° yana 0° | -60,0° | 1,3·10⁻¹⁰ | sınır uygulanmadı, komut aynen izlendi
sağ öne 0° yana 140° | 140,0° | 2,0·10⁻¹¹ | sınır uygulanmadı, komut aynen izlendi
sağ öne 0° yana -15° | -15,0° | 4,9·10⁻¹¹ | sınır uygulanmadı, komut aynen izlendi
sol öne 160° yana 0° | 160,0° | 2,3·10⁻¹¹ | sınır uygulanmadı, komut aynen izlendi
sol öne 180° yana 0° | 180,0° | 6,6·10⁻¹¹ | sınır uygulanmadı, komut aynen izlendi
sol öne -60° yana 0° | -60,0° | 1,3·10⁻¹⁰ | sınır uygulanmadı, komut aynen izlendi
sol öne 0° yana 140° | 140,0° | 2,0·10⁻¹¹ | sınır uygulanmadı, komut aynen izlendi
sol öne 0° yana -15° | -15,0° | 4,9·10⁻¹¹ | sınır uygulanmadı, komut aynen izlendi
sağ dirsek 120° bilek 0° | 120,0° | 3,0·10⁻¹¹ | sınır uygulanmadı, komut aynen izlendi
sağ dirsek -20° bilek 0° | -20,0° | 2,1·10⁻¹¹ | sınır uygulanmadı, komut aynen izlendi
sağ dirsek 0° bilek 120° | 120,0° | 8,1·10⁻¹² | sınır uygulanmadı, komut aynen izlendi
sol dirsek 120° bilek 0° | 120,0° | 3,1·10⁻¹¹ | sınır uygulanmadı, komut aynen izlendi
sol dirsek -20° bilek 0° | -20,0° | 2,1·10⁻¹¹ | sınır uygulanmadı, komut aynen izlendi
sol dirsek 0° bilek 120° | 120,0° | 7,8·10⁻¹² | sınır uygulanmadı, komut aynen izlendi
kafa pan 120° tilt 0° | 120,0° | 2,7·10⁻¹¹ | sınır uygulanmadı, komut aynen izlendi
kafa pan 180° tilt 0° | 180,0° | 3,0·10⁻¹¹ | sınır uygulanmadı, komut aynen izlendi
kafa pan 0° tilt 40° | 40,0° | 4,6·10⁻¹¹ | sınır uygulanmadı, komut aynen izlendi
kafa pan 0° tilt -35° | -35,0° | 2,9·10⁻¹² | sınır uygulanmadı, komut aynen izlendi

Elle verilen poz + solve() | Sınır içinde | Solve sonrası açı | Konum sapması mm
sağ öne 90° yana 45° | evet | öne 90° · yana 45° | 4,8·10⁻¹³
sağ öne 160° yana 0° | hayır | öne 160° · yana 0° | 7,1·10⁻¹³
sağ öne 0° yana 140° | hayır | öne 0° · yana 140° | 3,4·10⁻¹³
sağ öne -60° yana 0° | hayır | öne -60° · yana 0° | 7,0·10⁻¹³
sol öne 90° yana 45° | evet | öne 90° · yana 45° | 6,1·10⁻¹³
sol öne 160° yana 0° | hayır | öne 160° · yana 0° | 6,9·10⁻¹³
sol öne 0° yana 140° | hayır | öne 0° · yana 140° | 4,6·10⁻¹³
sol öne -60° yana 0° | hayır | öne -60° · yana 0° | 7,1·10⁻¹³
sağ dirsek 60° bilek 45° | evet | dirsek 60° · bilek 45° | 5,9·10⁻¹³
sağ dirsek 125° bilek 0° | hayır | dirsek 125° · bilek 0° | 3,8·10⁻¹³
sağ dirsek 30° bilek -110° | hayır | dirsek 30° · bilek -110° | 2,7·10⁻¹³
sol dirsek 60° bilek 45° | evet | dirsek 60° · bilek 45° | 5,8·10⁻¹³
sol dirsek 125° bilek 0° | hayır | dirsek 125° · bilek 0° | 2,8·10⁻¹³
sol dirsek 30° bilek -110° | hayır | dirsek 30° · bilek -110° | 2,6·10⁻¹³
kafa pan 45° tilt 20° | evet | pan 45° · tilt 20° | 6,1·10⁻¹³
kafa pan 120° tilt 0° | hayır | pan 120° · tilt 0° | 2,8·10⁻¹³
kafa pan 0° tilt 40° | hayır | pan 0° · tilt 40° | 2,5·10⁻¹³
teker ön sağ 30° ön sol -60° arka sağ 200° arka sol 0° | evet | ön sağ 30° · ön sol -60° · arka sağ -160° · arka sol 0° | 2,2·10⁻¹³

## GUI'de açılış ve sürükleme

montaj_gui_kontrol.py dosyayı FreeCAD arayüzünde hiçbir düzeltme yapmadan açtı: 907/907 parça ve 22 grup görünür, 22 eklemin hepsinin görünüm nesnesi var ve görünür (ViewProviderGroundedJoint, ViewProviderJoint), hepsi ağaçta seçilebiliyor, 14 döner eklemin (dirsek ve bilek dahil) işareti 3B görünümde tıklanınca eklemin kendisi seçiliyor. Robot montajı etkinleştirildi (çift tık karşılığı) ve kol, Qt fare olaylarıyla 3B görünümde sürüklendi. Simülasyon Kollari_oynat (14 hareket) görünüm nesnesiyle açılıyor.

Montaj etkin, eklem işaretleri görünür; sağ dirsek eklemi seçili (bağladığı üst kol ve ön kol vurgulu)

Montaj etkin, eklem işaretleri görünür; sağ dirsek eklemi seçili (bağladığı üst kol ve ön kol vurgulu)

Fareyle sürükleme: sağ kol yana 65° açıldı

Fareyle sürükleme: sağ kol yana 65° açıldı

Fareyle sürükleme: sağ dirsek 72° büküldü

Fareyle sürükleme: sağ dirsek 72° büküldü

Fareyle sürükleme: kafa boyun milinden tutulup pan döndürüldü

Fareyle sürükleme: kafa boyun milinden tutulup pan döndürüldü

Model ağacı: Robot montajı, Eklemler, 22 grup, Kollari_oynat simülasyonu

Model ağacı: Robot montajı, Eklemler, 22 grup, Kollari_oynat simülasyonu

### Sürükleme denemeleri

# | Kol | Deneme | Tutulan parça | Öne-arka (yol boyunca) | Yana (yol boyunca) | Dirsek (yol boyunca) | Bırakınca

1 | sağ | yana açma, dışarı | OmuzSag_P065 | 0,0° … 0,0° | 0,0° … 64,7° | 0,0° … 0,0° | öne 0,0° · yana 64,7° · dirsek 0,0°
2 | sağ | yana açma, daha dışarı | OmuzSag_P065 | 0,0° … 0,0° | 0,0° … 112,2° | 0,0° … 0,0° | öne 0,0° · yana 112,2° · dirsek 0,0°
3 | sağ | yana açma, çok dışarı (sınır 120) | OmuzSag_P065 | 0,0° … 90,1° | 0,0° … 120,0° | 0,0° … 105,0° | öne 0,5° · yana 120,0° · dirsek 0,2°
4 | sağ | yana açma, içeri (sınır 0) | OmuzSag_P065 | -0,1° … 0,0° | 0,0° … 0,0° | 0,0° … 0,2° | öne -0,1° · yana 0,0° · dirsek 0,2°
5 | sol | yana açma, dışarı | Kabuk_P007 | 0,0° … 0,0° | 0,0° … 33,7° | 0,0° … 0,0° | öne 0,0° · yana 33,7° · dirsek 0,0°
6 | sağ | öne kaldırma, kol tüpünden (yan görünüm) | OmuzSag_P065 | 0,0° … 0,0° | 0,0° … 0,0° | 0,0° … 0,0° | öne 0,0° · yana 0,0° · dirsek 0,0°
7 | sağ | öne kaldırma, göbekten (yan görünüm) | OmuzSag_P038 | -43,0° … 0,0° | 0,0° … 0,0° | 0,0° … 0,0° | öne -43,0° · yana 0,0° · dirsek 0,0°
8 | sağ | öne kaldırma, göbekten çok (sınır 135) | OmuzSag_P038 | -43,0° … 0,0° | 0,0° … 0,0° | 0,0° … 0,0° | öne -43,0° · yana 0,0° · dirsek 0,0°
9 | sağ | arkaya, göbekten (sınır -45) | OmuzSag_P038 | 0,0° … 97,8° | 0,0° … 0,0° | 0,0° … 0,0° | öne 97,8° · yana 0,0° · dirsek 0,0°
10 | sol | öne kaldırma, göbekten (yan görünüm) | OmuzSol_P038 | -43,0° … 0,0° | 0,0° … 0,0° | 0,0° … 0,0° | öne -43,0° · yana 0,0° · dirsek 0,0°
11 | sağ | dirsek bukme, on koldan (yan görünüm) | DirsekSag_P016 | 0,0° … 0,0° | 0,0° … 0,0° | 0,0° … 71,5° | öne 0,0° · yana 0,0° · dirsek 71,5°

### Kafa sürükleme denemeleri

# | Deneme | Tutulan parça | Pan (yol boyunca) | Tilt (yol boyunca) | Bırakınca

1 | pan: kafadan (tepeden) tutup yana | Kafa_P073 | 0,0° … 0,0° | 0,0° … 0,0° | pan 0,0° · tilt 0,0°
2 | pan: boyun milinden (onden) tutup sağa | Kafa_P035 | -3,4° … 0,0° | 0,0° … 0,0° | pan -3,4° · tilt 0,0°
3 | pan: boyun milinden çok sağa (sınır 90) | Kafa_P035 | -13,9° … 0,0° | 0,0° … 0,0° | pan -13,9° · tilt 0,0°
4 | pan: boyun milinden sola | Kafa_P035 | 0,0° … 3,5° | 0,0° … 0,0° | pan 3,5° · tilt 0,0°
5 | tilt: yüzden tutup aşağı | Kafa_P073 | 0,0° … 0,0° | 0,0° … 30,0° | pan 0,0° · tilt 30,0°
6 | tilt: çok (sınır -25...30) | Kafa_P073 | 0,0° … 0,0° | 0,0° … 30,0° | pan 0,0° · tilt 30,0°

Yana açma: sürüklemede 120°'de ve 0°'da duruyor. Öne-arka: göbekten sürüklemede −45° ile 135° arasında kaldı; kol tüpünden sürüklemede dönmedi (açık işler). Dirsek: ön koldan sürüklemede döndü ve 0…105° içinde kaldı. Kol uzadığı için yana açmayı sınıra zorlayan sürüklemede çözücü serbest zinciri (öne-arka, dirsek) de sallayabiliyor; bırakınca açılar yine sınırlar içinde.

## Çakışma (carpisma.py, bölümlü tam koşu)

2026-10-08: birlestirilmemis, tek seferlik tam kosu (kosu 20261008-221731, 2026-10-08T22:18:16 ... 2026-10-08T23:44:43). Dokuz bolum (statik, omuz, kol_sag, kol_sol, kolkol, kafa_sabit, kafa_sag, kafa_sol, taban) ayri freecadcmd sureclerinde sirayla kostu; her bolumun suresi ve tepe bellegi 'bolumler'de. Tum bolumler ayni kaynak dosyalarla (md5 ozetleri 'kaynak') kostu; onceki kosulardan veri alinmadi. Her bölüm ayrı bir freecadcmd sürecinde sırayla koştu (python carpisma_kos.py); süre ve tepe bellek (çalışma kümesi) bölüm başına:

Bölüm | Durum | Başlangıç | Süre (yükleme + tarama) | Tepe bellek
ev pozu + kütle | tamam | 2026-10-08T22:18:16 | 44 s + 10 s | 510 MB
omuz pozları | tamam | 2026-10-08T22:19:06 | 39 s + 1.693 s | 499 MB
sağ kol zinciri | tamam | 2026-10-08T22:48:00 | 37 s + 301 s | 510 MB
sol kol zinciri | tamam | 2026-10-08T22:53:35 | 34 s + 298 s | 499 MB
kol ↔ kol | tamam | 2026-10-08T22:58:38 | 5 s + 29 s | 125 MB
kafa × sabit | tamam | 2026-10-08T22:59:41 | 33 s + 19 s | 503 MB
kafa × sağ kol | tamam | 2026-10-08T23:00:06 | 5 s + 1.099 s | 647 MB
kafa × sol kol | tamam | 2026-10-08T23:18:32 | 7 s + 1.467 s | 644 MB
taban | tamam | 2026-10-08T23:43:53 | 54 s + 51 s | 553 MB

### Omuz taraması (yalnız omuz parçaları)

Hareketli modül | Poz | Çakışan poz | Eklem aralığında | En küçük boşluk | En yakın çift
Sağ omuz | 875 | 88 | 0 | 0,0 mm | Kol catali ↔ kabuk / Omuz bandi sag, öne -60° yana -20°
Sol omuz | 875 | 88 | 0 | 0,0 mm | Kol catali ↔ kabuk / Omuz bandi sol, öne -60° yana -20°

Omuz tarama aralığı: omuz_montaj taramasi: one-arka -60...180, yana -20...150 (5-10 derece adim). Aralık dışındaki çakışmalar eklem sınırlarıyla engelleniyor.

### Kol zinciri taraması (omuz × dirsek × bilek, dirsek parçaları)

Kaba ızgara: öne-arka -45…135° (15° adım), yana 0…120° (15°), dirsek [0, 30, 60, 90, 105], bilek [-90, 0, 90] = kol başına 1755 poz; aralık dışı halka 279 poz; 5 mm'nin altında boşluk kalan alt pozların çevresi 5° adımla yeniden tarandı (188 alt poz). Eklem aralığında çakışma: sağ 0, sol 0; aralık dışı halkada sağ 63, sol 63 poz (yana −10°: el kabuğa değiyor; omuz yana sınırı 0° bunu engelliyor). Kol ↔ kol (iki kol aynı anda, 227 poz çifti: simetrik, zıt, birlikte öne): çakışma 0, en küçük boşluk 290 mm.

Kol | Hedef | En küçük boşluk (eklem aralığında) | Parça çifti | Poz
Sağ kol | kabuk | 3,8 mm | Dirsek catali ↔ Gogus bandi sag | öne 40° yana 0°
Sağ kol | omuz_sag govde | 69,7 mm | Dirsek catali ↔ Omuz yuvasi | öne -30° yana 0°
Sağ kol | omuz_sag gobek | 81,4 mm | Dirsek catali ↔ Omuz gobegi | öne 120° yana 120°
Sağ kol | iskelet | 102,7 mm | Dirsek catali ↔ Omuz traversi | öne -45° yana 0°
Sol kol | kabuk | 3,8 mm | Dirsek catali ↔ Gogus bandi sol | öne 40° yana 0°
Sol kol | omuz_sol govde | 69,7 mm | Dirsek catali ↔ Omuz yuvasi | öne -30° yana 0°
Sol kol | omuz_sol gobek | 81,4 mm | Dirsek catali ↔ Omuz gobegi | öne 120° yana 120°
Sol kol | iskelet | 102,7 mm | Dirsek catali ↔ Omuz traversi | öne -45° yana 0°

### Kafa taraması (pan × tilt; sabit modüller ve iki kolun pozlarıyla)

Kafa pan -180…165° (15°) × tilt [-25, -10, 0, 10, 20, 30, 40] = 168 kafa pozu; eklem aralığı pan -90…90°, tilt -25…30°. Her kol: kol zinciri kaba ızgarası + 15 jest pozu = 1770 kol pozu × kafa pozları (sıkı sınır kutusu ön elemesi, 5 mm altındaki her aday tam ölçüldü, çakışan / 5 mm altı çiftlerin çevresi bir tur ±10° içinde 5° adımla; ardından yasak bölgenin sınırı: çakışan her çiftin eksen komşuları 5° (bilek 15°) adımla, yeni çakışma kalmayana dek (sağ 8 tur, sol 8 tur; yakınsadı)). Eklem aralığında: kafa × sabit modüller 0 çakışma; kafa × kol sağ 603, sol 603 çakışan poz çifti. Süre 2.585 s.

Tarama | Hedef | En küçük boşluk (eklem aralığında) | Parça çifti | Poz
Kafa | iskelet (kafa govdesi) | 0,0 mm | Boyun plakasi ↔ Omuz traversi | sabit boyun
Kafa | kabuk (kafa govdesi) | 8,4 mm | Boyun plakasi ↔ Omuz bandi sag | sabit boyun
Kafa | omuz_sag govde (kafa govdesi) | 22,0 mm | Boyun plakasi ↔ Omuz yuvasi | sabit boyun
Kafa | omuz_sol govde (kafa govdesi) | 22,0 mm | Boyun plakasi ↔ Omuz yuvasi | sabit boyun
Kafa | iskelet | 43,0 mm | Pan horn merkez vidasi M3 ↔ Omuz traversi | pan -90°
Kafa | omuz_sag govde | 51,6 mm | Arka kafa kabugu ↔ Yuva baglanti civatasi M6x16 | pan -30° tilt -25°
Kafa | omuz_sol govde | 51,6 mm | Arka kafa kabugu ↔ Yuva baglanti civatasi M6x16 | pan 30° tilt -25°
Kafa | kabuk | 54,2 mm | Arka kafa kabugu ↔ Omuz bandi sag | pan -90° tilt -25°
Kafa ↔ sağ kol | el | çakışma | El ↔ Yuz kabugu (on) | kol (135° / 0° / 90° / -90°); kafa 45° / 30°
Kafa ↔ sağ kol | on kol | 25,7 mm | On kol govdesi ↔ Vizor (siyah akrilik) | kol (135° / 0° / 90°); kafa 30° / 30°
Kafa ↔ sağ kol | dirsek catali | 55,4 mm | Dirsek catali ↔ Vizor (siyah akrilik) | kol (135° / 0°); kafa 15° / 30°
Kafa ↔ sağ kol | omuz | 58,8 mm | Ust kol tupu ↔ Yuz kabugu (on) | kol (135° / 0°); kafa 15° / 20°
Kafa ↔ sol kol | el | çakışma | El ↔ Yuz kabugu (on) | kol (135° / 0° / 90° / -90°); kafa -45° / 30°
Kafa ↔ sol kol | on kol | 25,7 mm | On kol govdesi ↔ Vizor (siyah akrilik) | kol (135° / 0° / 90°); kafa -30° / 30°
Kafa ↔ sol kol | dirsek catali | 55,4 mm | Dirsek catali ↔ Vizor (siyah akrilik) | kol (135° / 0°); kafa -15° / 30°
Kafa ↔ sol kol | omuz | 58,8 mm | Ust kol tupu ↔ Yuz kabugu (on) | kol (135° / 0°); kafa -15° / 20°

Yasak poz bölgesi (yazılım sınırı): aşağıdaki kol pozlarında kafa belirtilen açılara dönmemeli. Ayrıntı ve jest pozları kafa/rapor.html'de.

Kol, grup | Çakışan alt poz | Kol açıları (aralık) | Kafa (pan / tilt aralığı) | Çakışan çift
sağ kol, El | 198 | öne 125…135° · yana 0…0° · dirsek 70…105° · bilek -90…90° | pan 30…55°, tilt 25…30° | El / Yuz kabugu (on)
sol kol, El | 198 | öne 125…135° · yana 0…0° · dirsek 70…105° · bilek -90…90° | pan -55…-30°, tilt 25…30° | El / Yuz kabugu (on)

### Taban taraması

Ev pozu: taban ↔ her modül; kutusu kesişen her çift gerçek kesişimle (common) sınandı, 1 mm içindekiler ölçüldü (temas = 0 mm, hacim ≤ 0,5 mm³).

Modül | Kutu kesişen çift | Çakışma | Temas | En küçük boşluk | En yakın çift
İskelet | 97 | 0 | 44 | 0,0 mm | Alt plaka ↔ Sase uzun rayi sag
Sağ omuz | 0 | 0 | 0 | 550,9 mm | Acil stop mantari + bilezik ↔ Ust kol tupu
Sol omuz | 0 | 0 | 0 | 582,8 mm | Ana anahtar ASW-A01 govdesi (tahmini zarf) ↔ Ust kol tupu
Kabuk | 365 | 0 | 1 | 0,0 mm | Acil stop mantari + bilezik ↔ Etek arka sag
Sağ dirsek | 0 | 0 | 0 | 377,1 mm | Acil stop mantari + bilezik ↔ El
Sol dirsek | 0 | 0 | 0 | 407,3 mm | Ana anahtar ASW-A01 govdesi (tahmini zarf) ↔ El
Kafa | 0 | 0 | 0 | 695,6 mm | Acil stop mantari + bilezik ↔ Cekic somun M6 (travers ust kanali)

Kollar × taban: her kolun kol zinciri ızgarası (1755 poz) + aralık dışı halka (279) + 15 jest pozunun tüm alt pozları × taban parçaları, ana anahtar düğmesi gösterimi ve etek; kategori başına en küçük boşluk dal-sınırla, çevresi 5° adımla. Eklem aralığında çakışma sağ 0, sol 0; kolun en alt noktası y ≈ 626 mm, tabanın en üstü y = 290 mm.

Kol | Hedef | En küçük boşluk (eklem aralığında) | Parça çifti | Kol pozu (öne / yana / dirsek / bilek)
Sağ kol | etek (kabuk) | 365,4 mm | El ↔ Etek orta sag | 0° / 0° / 10° / -15°
Sağ kol | acil stop | 367,0 mm | El ↔ Acil stop mantari + bilezik | -10° / 0° / 0° / -75°
Sağ kol | ana anahtar dugmesi | 431,4 mm | El ↔ Ana anahtar dugmesi (gosterim, kabuk deligi gerekir) | -20° / 0° / 0° / 75°
Sağ kol | taban diger | 432,5 mm | El ↔ ESP32 DevKit 30 pin | 5° / 0° / 10° / 0°
Sağ kol | sonar | 543,7 mm | El ↔ Sonar tutucu sag | 15° / 0° / 10° / 0°
Sol kol | etek (kabuk) | 365,9 mm | El ↔ Etek orta sol | 5° / 0° / 5° / -15°
Sol kol | ana anahtar dugmesi | 376,0 mm | El ↔ Ana anahtar dugmesi (gosterim, kabuk deligi gerekir) | -10° / 0° / 0° / -75°
Sol kol | taban diger | 398,5 mm | El ↔ Ana anahtar ASW-A01 govdesi (tahmini zarf) | -10° / 0° / 5° / -90°
Sol kol | acil stop | 420,9 mm | El ↔ Acil stop mantari + bilezik | -20° / 0° / 0° / 75°
Sol kol | sonar | 543,7 mm | El ↔ Sonar tutucu sol | 15° / 0° / 10° / 0°

Kafa × taban: kafanın tüm pan × tilt pozlarında en alt noktası y = 965 mm, tabanın en üstü 290 mm: aralarında 675 mm; ölçüm gerekmedi (sınır kutusu).

Ev pozunda 0 çakışma (693 sınır kutusu kesişen çift gerçek kesişimle sınandı). Eklem aralığında toplam 1206, aralık dışı dahil 1590. Tüm modüller çizildi: ayrılmış bölge kalmadı, her modül gerçek geometrisiyle tarandı.

## FreeCAD'de kolları oynatmak

1. FreeCAD 1.1'de Dosya → Aç ile tasarim/freecad/montaj/robot-montaj.FCStd dosyasını aç. Model ağacında Robot montajı, altında Eklemler (22 eklem) ve 22 parça grubu görünür.
2. Ağaçta Robot'a çift tıkla: montaj etkinleşir (Assembly tezgâhı açılır, eklem işaretleri görünür).
3. Kolu fareyle tut ve sürükle: yana açma için mavi üst kol tüpünden, öne kaldırma için omuz göbeğinden (mavi kutu) tut. Eklem sınırlarında kol durur. Göbek eksene yakın olduğu için küçük fare hareketi büyük dönüş verir; yavaş sürükle. Dirsek için ön kolu (mavi, servolu gövde) tutup öne-yukarı sürükle; bilek fareyle zor tutulur (el küçük), simülasyonla oynat.
4. Kafa: tilt için kafayı yüzünün yanından tutup aşağı-yukarı sürükle (−25…30°'de durur). Pan için kafanın altındaki boyun milini (turuncu, kabuk kapağıyla kafa arasında) tut ve yana sürükle: mil eksene yakın, küçük fare hareketi büyük dönüş verir; kafadan tutunca yalnız tilt döner. Kesin açı için simülasyon.
5. Hazır hareket için ağaçta Simulations → Kollari_oynat'a çift tıkla, açılan panelde Run Kinematics (kinematiği çalıştır) düğmesine, sonra ▶ (ileri oynat) düğmesine bas. Paneli OK ile kapat. Kollar son karede kalır; sıfır pozuna dönmek için dosyayı kaydetmeden kapatıp yeniden aç.

## Kararlar

- Sol omuz gerçek aynalı geometri: Placement aynalama yapamaz; sağ omuzun her parçasının şekli mirror ile X'te aynalanıp konumuna kopyalanarak taşındı (transformShape(m, True)). Hacim farkı 3,8·10<sup>-10</sup> mm³, aynalı parçaların kendi kütle merkezi ile aynalanmış yerel merkez farkı 5,9·10<sup>-13</sup> mm. Sol parçaların adı "(sol)" ile bitiyor, Aynali özelliği doğru.
- Yerleşim yalnız arayuz.MODULLER'den: Ana montajda tek bir yerleşim sayısı yazılmadı. Omuz yuvası sabit eklem noktası arayuz.OMUZ_YUVA_X ortası (x = ±86,5). Eklem eksenleri ve sınırları omuz/omuz-montaj.FCStd'deki eklemlerden okunuyor, solda eksen eksenel vektör olarak aynalanıyor (a′ = −M·a): öne-arka ekseni her iki kolda −X, yana açma ekseni sağda +Z, solda −Z. Böylece pozitif açı iki kolda da aynı hareketi veriyor.
- Öne-arka sınırı neden −45…135°, serbest aralık −60…180° iken: −60…180° omuz taramasında *çarpışmanın olmadığı* aralık (geometri sınırı). Eklem sınırı ise servonun dönebildiği aralık: DS3218MG'nin 180° sürümü, horn kol aşağıdayken servo 45° konumunda takılıyor (omuz montaj sırası, 5. adım). Servo 0…180° → eklem −45…135°. Yana açmada sınır 0…120° (omuz_montaj); 0°'nin altında kol gövdeye çarpıyor (omuz taraması yana −20…−5°). 270° servo alınırsa sınırlar −60…180°'e kadar açılabilir (geometri izin veriyor); o zaman omuz_montaj.py güncellenip ana montaj yeniden kurulur.
- Dirsek modülü omuz zincirine bağlı: her dirsek çatalı omuzun Kol grubuna sabit eklemle (üst kol tüpünün ucu, pim + sıkma bileziği) bağlı; her kolda üst kol → ön kol (dirsek, 0…105°) ve ön kol → el (bilek, −90…90°) döner eklemleri. Eksen ve sınırlar dirsek/dirsek-montaj.FCStd'den okunuyor ve arayuz.DIRSEK ile karşılaştırılıyor; solda eksen aynalanıyor. Pozitif dirsek açısı iki kolda ön kolu öne büker, pozitif bilek açısı avucu öne çevirir. Sol dirsek sağın gerçek aynalı geometrisi.
- Kafa modülü: kafanın sabit boynu (boyun plakası + servo/rulman yuvası + pan servosu) traverse sabit eklemle bağlı; sabit boyun → pan grubu (pan, −90…90°, eksen +Y) ve pan grubu → kafa (tilt, −25…30°, eksen +X, y = 1.105, z = 25) döner eklemleri. Eksen ve sınırlar kafa/kafa-montaj.FCStd'den okunup arayuz.KAFA ile karşılaştırılıyor. Ana montajda gruplar Kafa_Govde / Kafa_Boyun / Kafa_Bas (eklem adları Kafa_Pan / Kafa_Tilt ile çakışmasın diye). Kablo demeti gösterimi (Referans, 0 g) ana montajda yok.
- Travers bir kez sayılıyor: Omuz modülünün içindeki 200 mm traversi iskeletin parçası; ana montajda yalnız iskeletinki var. Omuzdaki kabuk duvarı (referans, 0 g) ana montajda yok; yerini gerçek kabuk modülü aldı (kabuk/). Parça sayısı 907 = iskelet 59 + 2 x (omuz 70 - travers - kabuk referansi) + kabuk 202 + dirsek_sag 53 + dirsek_sol 53 + kafa 98 + taban 306.
- Taban modülü: taban gövdesi (plakalar, motorlar, akü, güç, elektronik katı, sonar, acil stop) uzun raya sabit eklemle bağlı; her köşede teker grubu (teker + kaplin + M4 eksenel vida ve pulu) taban gövdesine sınırsız döner eklemle (motor mili ekseni +X, teker merkezi x ±178, y 62,5, z ±185). Pozitif açı ileri yuvarlanma (tekerin alt noktası geri gider). Motor gövdesi ve mili tek katı olduğu için motor gövdede kalıyor. Kablo yolu şemaları ve ana anahtar düğmesi gösterimi (Referans, 0 g) ana montajda yok.
- Eklem yapısı: İskelet zemine sabit (grounded); her omuz gövdesi, kabuk, kafanın boynu ve taban gövdesi iskelete sabit eklemle bağlı; her omuzda gövde → göbek (öne-arka) ve göbek → kol (yana açma), her dirsekte üst kol → ön kol (dirsek) ve ön kol → el (bilek) döner eklemleri; kafada pan ve tilt; tabanda 4 teker. Serbestlik: 14 (her kolda 4, kafada 2, tekerlerde 4).

## Açık işler

- Eklem sınırları çözücüde zorlanmıyor: FreeCAD 1.1'de sınırlar yalnız fareyle sürüklemede uygulanıyor (yana 0…120°, öne −45…135° aşılmadı). Simülasyon (Motion) ve solve() sınır dışı açıyı aynen kabul ediyor (öne 160°, 180°, −60°; yana 140°, −15°). Simülasyon formülü yazarken sınırları elle gözet; robot yazılımında servo açısı ayrıca sınırlanmalı.
- Öne kaldırma kol tüpünden sürüklenmiyor: Kol aşağıdayken üst kol tüpünü tutup sürüklemek öne-arka eksenini döndürmedi (yalnız yana açma döndü). Göbekten tutunca dönüyor ama göbek eksene yakın (≈ 40 mm) olduğu için hareket sıçramalı, serbest kol da salınıyor. Kesin açı için simülasyon veya eklem açısını betikle ver.
- Sol kolda servo dönüş yönü ters: Sol S1 ve S2 servoları aynalı yerleşimde; aynı eklem açısı (ör. öne +30°) için sol servo kendi mil yönüne göre ters döner. Yazılımda sol servoların komut işareti çevrilmeli, horn takma açısı da aynalı (sol S1 135° konumunda takılır) (tahmini; servo montajında doğrulanmalı).
- Sol baskı parçaları aynalı basılmalı: Omuz yuvası, rulman kapağı, omuz göbeği, kol çatalı ve tüp sağın aynası. Dilimleyicide STL'ler X'te aynalanarak basılır (omuz/stl/ yalnız sağ). Servo, horn, rulman ve cıvatalar simetrik kabul edildi: DS3218MG gövdesi genişlik yönünde simetrik, aynası 180° çevrilmiş servo ile aynı (tahmini; kablo çıkışı tarafı farklı olabilir).
- Kafa-kol yasak pozları yazılımda uygulanmalı: carpisma.py kafa taramasında bulunan kol pozu × kafa açısı birleşimleri (yukarıdaki tablo, ayrıntı kafa/rapor.html) eklem sınırlarıyla değil, ancak robot yazılımında (kol pozuna bağlı kafa açısı sınırı ya da hareket sırası) engellenebilir.
- Pan fareyle zor sürükleniyor: pan grubu kafanın altında kalıyor; kafadan tutunca yalnız tilt dönüyor, boyun milinden tutunca pan dönüyor ama mil eksene yakın (≈ 20 mm) olduğu için hareket küçük ve sıçramalı. Pan açısını simülasyonla ya da betikle ver.
- Bilek fareyle zor sürükleniyor: el küçük ve ön kol ekseninde döndüğü için 3B görünümde tutup çevirmek pratik değil; bilek açısını simülasyonla (Kollari_oynat) ya da betikle ver.
- Montaj dosyası iki adımda üretiliyor: ana_montaj.py (arayüzsüz) dosyayı kurar, montaj_gorsel.py (GUI) eklem görünüm nesnelerini ve simülasyonu ekleyip yeniden kaydeder. Yalnız ana_montaj.py çalıştırılırsa dosya açıldığında eklem işaretleri görünmez.
- Kablo payı montajda yok: montaj kütlesi 21,26 kg (parçalar); taban raporunun 400 g kablo payı (tahmini, parça listesine girmiyor) eklenince 21,66 kg, AM (-0,4; 370,5; -14,4) mm: taban raporundaki devrilme hesabının girdisiyle aynı (tutarlı).
- Teker eklemleri serbest: simülasyonda sınırsız dönüyor (tam tur ve üstü doğrulandı); gerçek robotta tekerleri JGB37 + enkoder sürer, montajdaki eklem yalnız görsel/kinematik.

## Dosyalar ve çalıştırma sırası

- robot-montaj.FCStd (Assembly, 22 grup, 22 eklem, Kollari_oynat simülasyonu) · robot-montaj.step (gruplar adlarıyla, 907 katı) · montaj-analiz.json · eklem-dogrulama.json · gui-kontrol.json · gorsel/
- moduller.py (modül listesi + yükleyiciler + aynalama) → ana_montaj.py (freecadcmd) → montaj_gorsel.py (freecad.exe; dosyayı GUI'den yeniden kaydeder) → montaj_gui_kontrol.py (freecad.exe) → eklem_dogrulama.py (freecadcmd) → ../carpisma_kos.py (bölümlü ../carpisma.py) → montaj_rapor.py (sistem Python'u)

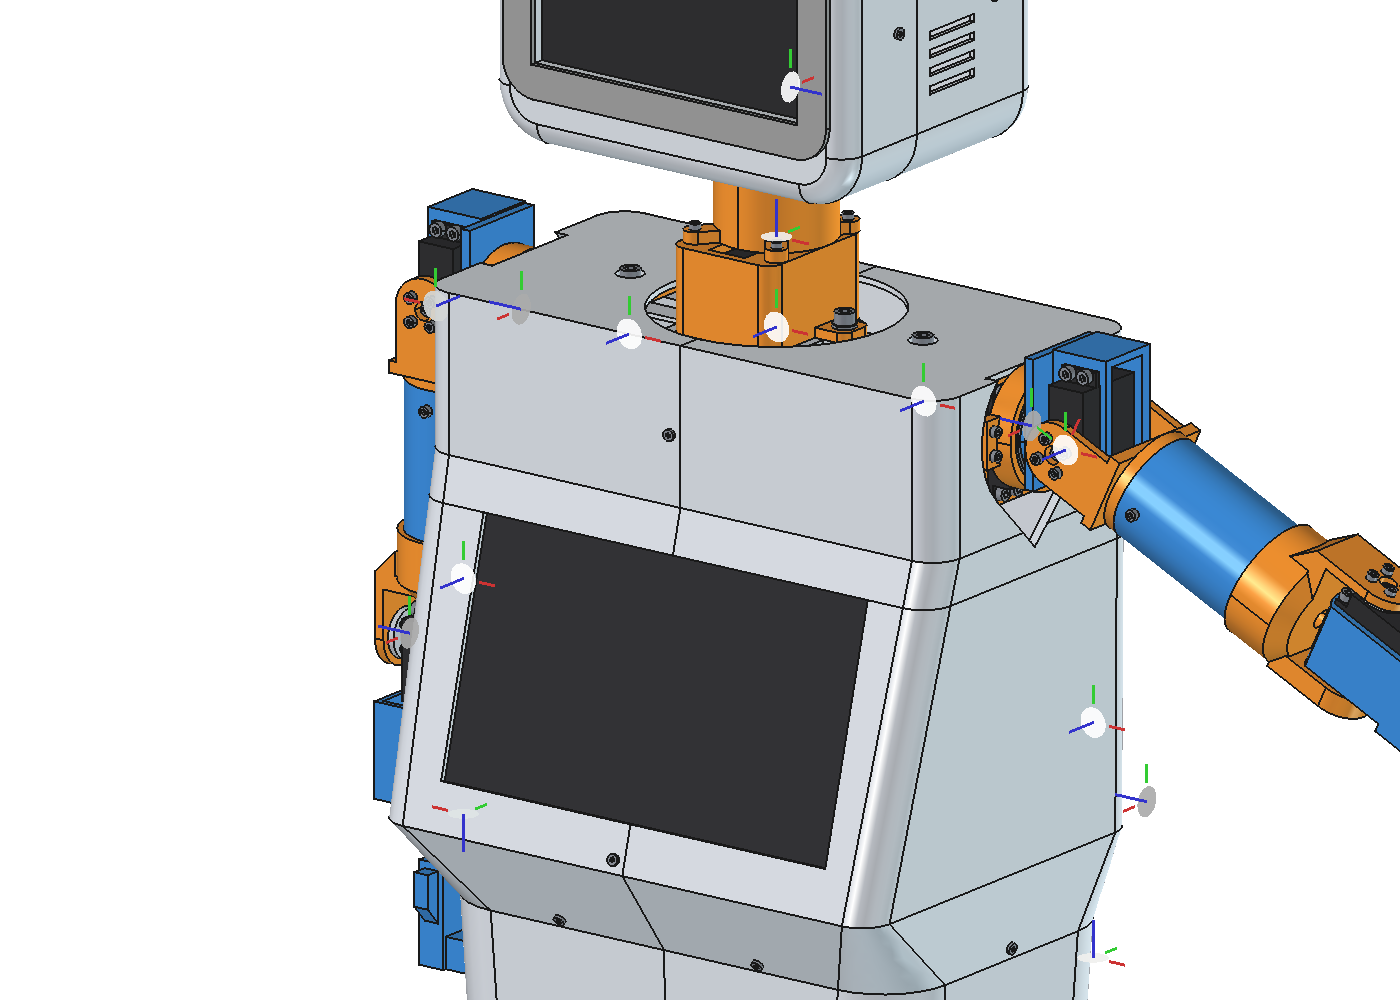
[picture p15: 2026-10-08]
tasarim/freecad/montaj/gorsel/montaj-gui-surukleme.png

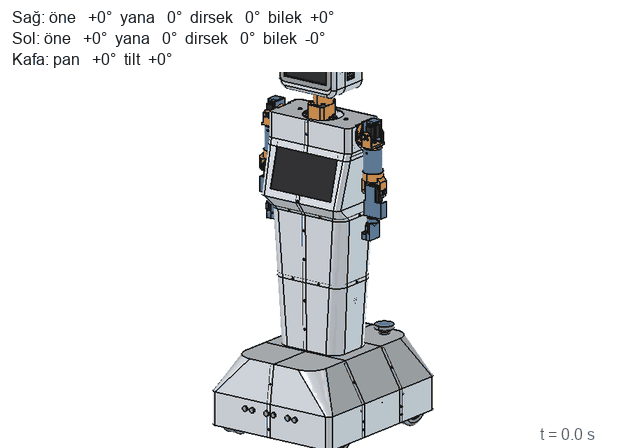
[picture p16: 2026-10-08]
tasarim/freecad/montaj/gorsel/montaj-hareket.gif

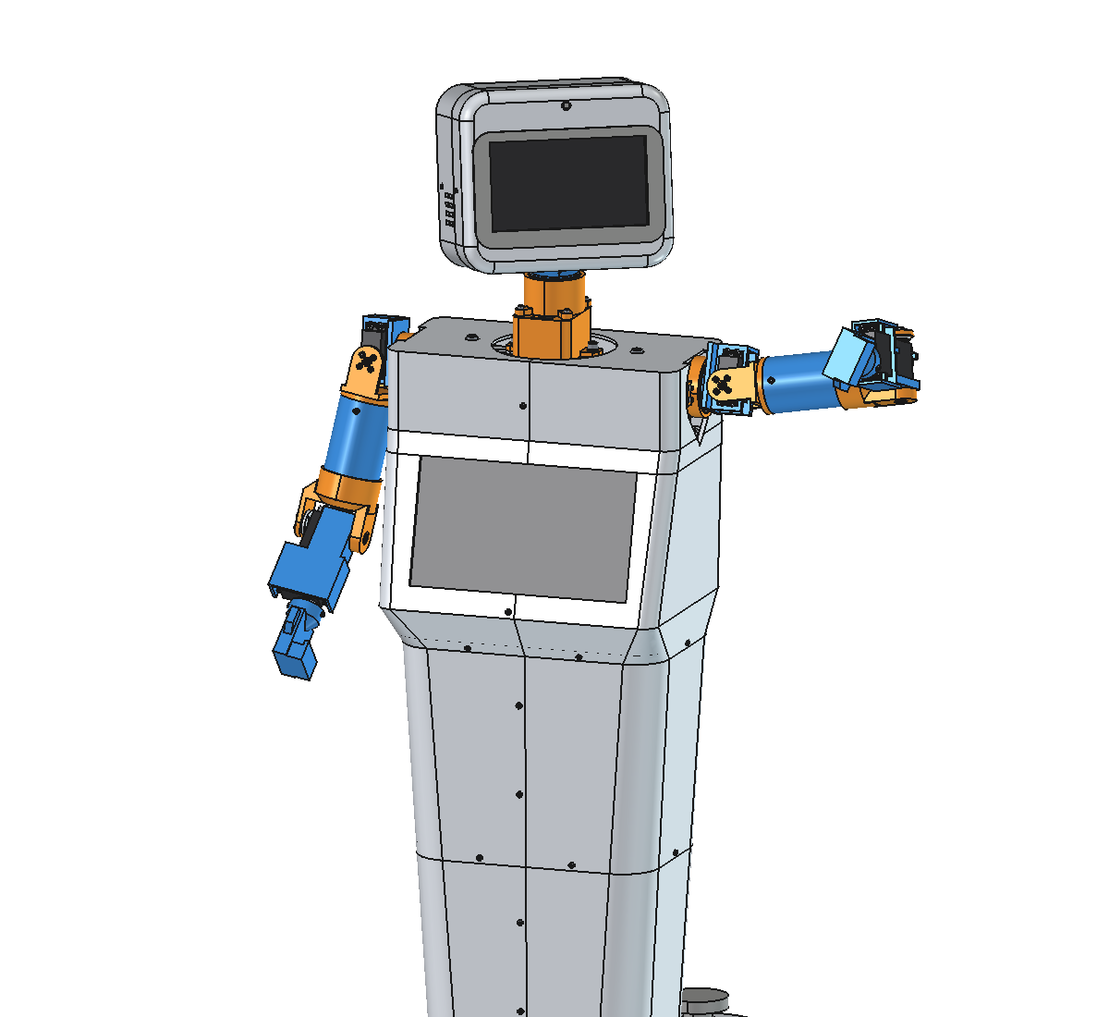
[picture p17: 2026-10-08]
tasarim/freecad/montaj/gorsel/montaj-poz-selam.png

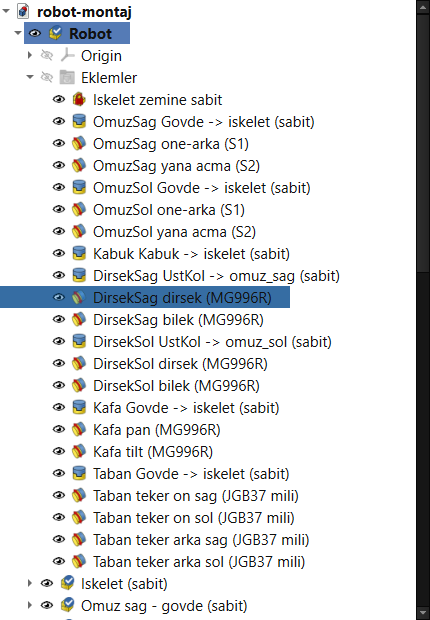
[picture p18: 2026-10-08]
tasarim/freecad/montaj/gorsel/montaj-gui-agac.png

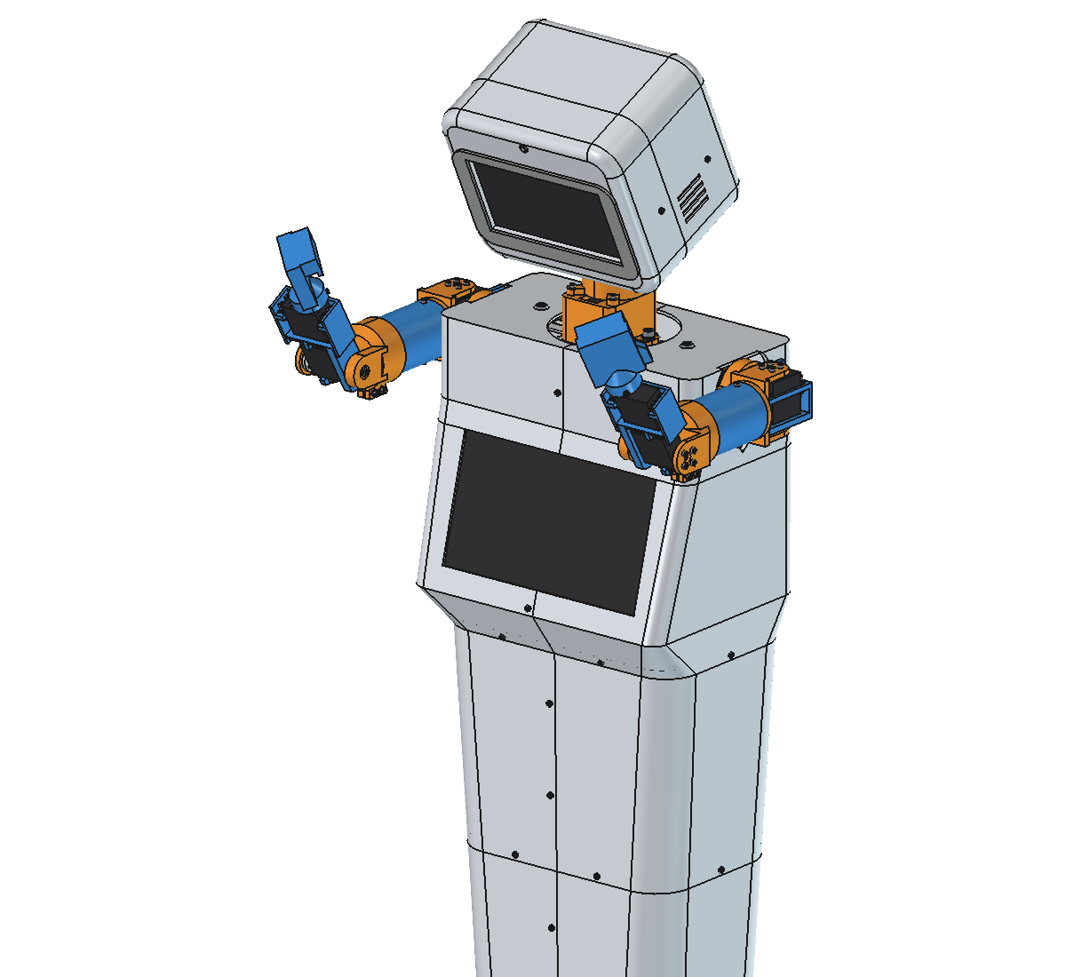
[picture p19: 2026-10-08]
tasarim/freecad/montaj/gorsel/montaj-poz-one.png

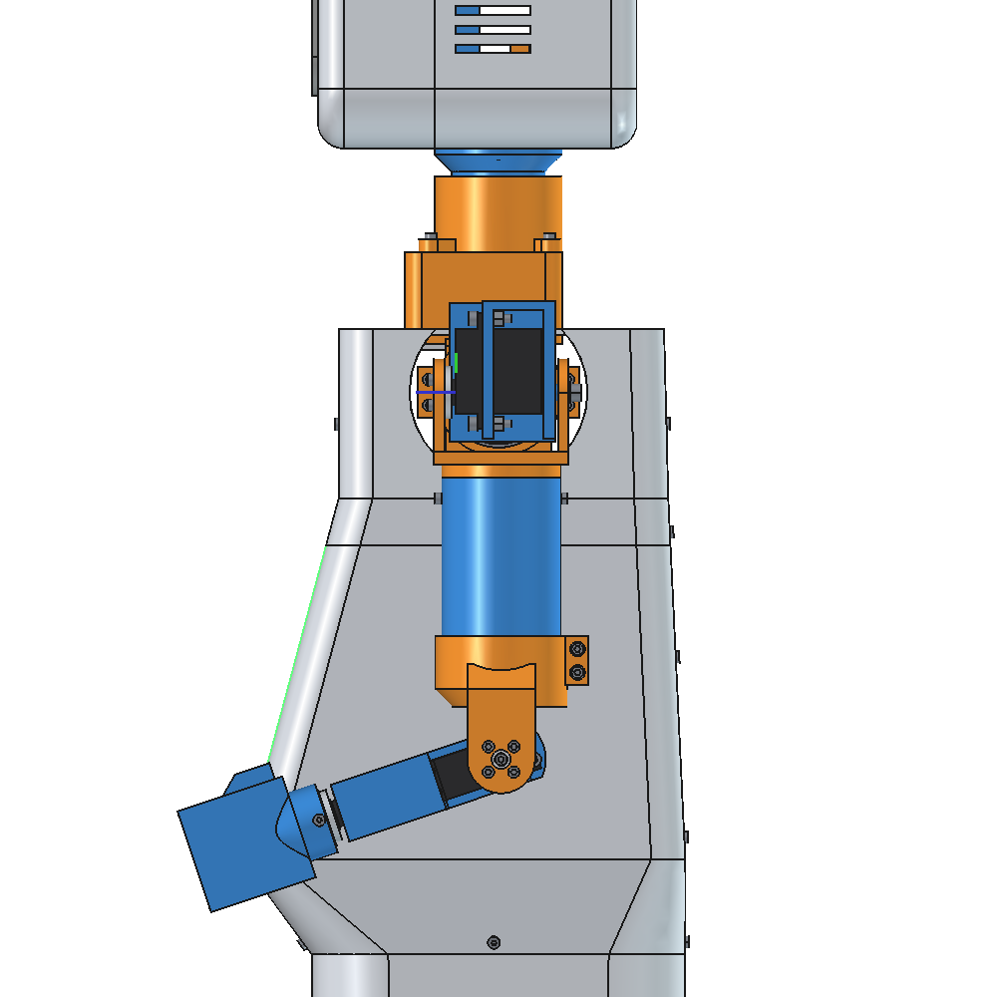
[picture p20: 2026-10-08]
tasarim/freecad/montaj/gorsel/montaj-gui-dirsek.png

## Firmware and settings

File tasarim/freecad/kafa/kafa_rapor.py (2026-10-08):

# Kafa modulu raporu (rapor.html, gorseller gomulu). Sistem Python'u ile calisir (FreeCAD gerekmez).
# Girdiler: kafa-analiz.json (kafa_montaj.py), gorsel/*.png (kafa_gorsel.py), ../arayuz.py.
# 2. asama: ../carpisma-sonuc.json (kafa_tarama), ../montaj/montaj-analiz.json, eklem-dogrulama.json, gui-kontrol.json ve
# ../montaj/gorsel/montaj-kafa*.png varsa "Moduller arasi carpisma ve ana montaj" bolumu doldurulur.
import os, sys, json, base64, html

HERE = os.path.dirname(os.path.abspath(__file__))
UST = os.path.dirname(HERE)
sys.path.insert(0, UST)
import arayuz as A

G = os.path.join(HERE, "gorsel")
d = json.load(open(os.path.join(HERE, "kafa-analiz.json"), encoding="utf-8"))
K = A.KAFA
Y = A.YAZICI


def esc(s):
    return html.escape(str(s))


def sayi(x, n=1):
    s = ("%." + str(n) + "f") % x
    tam, _, ond = s.partition(".")
    neg = tam.startswith("-")
    tam = tam.lstrip("-")
    gr = []
    while len(tam) > 3:
        gr.insert(0, tam[-3:])
        tam = tam[:-3]
    gr.insert(0, tam)
    return ("−" if neg and s.strip("-0.,") else "") + ".".join(gr) + ("," + ond if ond else "")


def img64(ad):
    return "data:image/png;base64," + base64.b64encode(open(os.path.join(G, ad), "rb").read()).decode()


def tablo(baslik, satirlar, sinif=""):
    h = ["<table class='%s'><tr>" % sinif + "".join("<th>%s</th>" % esc(b) for b in baslik) + "</tr>"]
    for s in satirlar:
        h.append("<tr>" + "".join("<td>%s</td>" % x for x in s) + "</tr>")
    h.append("</table>")
    return "".join(h)


def md(s):
    """**kalin** ve `kod` -> HTML."""
    s = esc(s)
    out, b, c = [], False, False
    i = 0
    while i < len(s):
        if s.startswith("**", i):
            out.append("</b>" if b else "<b>")
            b = not b
            i += 2
        elif s[i] == "`":
            out.append("</code>" if c else "<code>")
            c = not c
            i += 1
        else:
            out.append(s[i])
            i += 1
    return "".join(out)


OK = "<span class='ok'>tamam</span>"
NO = "<span class='no'>HATA</span>"
TR = {"Servo yuvasi": "Servo yuvası", "Rulman yuvasi": "Rulman yuvası", "Boyun mili": "Boyun mili", "Egme catali": "Eğme çatalı",
      "Kafa iskeleti": "Kafa iskeleti", "Yuz kabugu (on)": "Yüz kabuğu (ön)", "Arka kafa kabugu": "Arka kafa kabuğu",
      "MG996R servo": "MG996R servo (180°)", "25T aluminyum disk horn": "25T alüminyum disk horn",
      "M3x5 horn vidasi (servo ile)": "M3×5 horn vidası (servo ile gelir)", "625ZZ rulman 5x16x5": "625ZZ rulman 5×16×5",
      "6808-2RS rulman 40x52x7": "6808-2RS rulman 40×52×7", "M3 isil gomme somun": "M3 ısıl gömme somun",
      "M5 isil gomme somun": "M5 ısıl gömme somun", "M6 cekic somun (kanal 10)": "M6 çekiç somun (kanal 10)",
      "Boyun plakasi 3 mm Al (lazer/su jeti)": "Boyun plakası, 3 mm Al (lazer / su jeti)",
      "Vizor 3 mm siyah akrilik 190x115 (lazer)": "Vizör, 3 mm parlak siyah akrilik 190 × 115 (lazer)",
      "Waveshare 7in HDMI LCD (C) 1024x600": "Waveshare 7\" HDMI LCD (C) 1024 × 600 (yüz ekranı)",
      "Raspberry Pi Camera Module 3": "Raspberry Pi Camera Module 3", "M2x8 PT vida (plastik icin)": "M2×8 PT vida (plastik için)",
      "M4 DIN 985 kontra somun": "M4 DIN 985 kontra somun",
      "Pan servosu kulagi": "Pan servosu kulağı → servo yuvası", "Boyun plakasi -> traverse": "Boyun plakası + servo yuvası → traverse",
      "Rulman yuvasi -> servo yuvasi": "Rulman yuvası → servo yuvası", "Boyun mili -> pan horn": "Boyun mili → pan horn'u",
      "Egme catali -> boyun mili": "Eğme çatalı → boyun mili flanşı", "Tilt servosu kulagi": "Tilt servosu kulağı → çatal",
      "Kafa iskeleti sag yanak -> tilt horn": "Kafa iskeleti sağ yanağı → tilt horn'u",
      "Tilt pimi (servo karsi yatagi)": "Tilt pimi (servo karşı yatağı, 625ZZ)", "Kafa kabugu -> kafa tablasi": "Kafa kabuğu → kafa tablası",
      "LCD kulagi -> on kabuk boss'u": "LCD kulağı → ön kabuk boss'u", "Kamera -> on kabuk boss'u": "Kamera → ön kabuk boss'u",
      "Eksen hizasi ve oturmalar": "Eksen hizası ve oturmalar"}


def tr(s):
    s = TR.get(s, s)
    return s.replace("x", "×") if (s[:1] == "M" and ("DIN" in s or "ISO" in s)) else s


def pay(x):
    cls = "ok" if x >= 2 else ("no" if x < 1.2 else "uy")
    return "<span class='%s'>%s×</span>" % (cls, sayi(x, 1))


# ---------------------------------------------------------------- ozetler
bag = d["baglanti_kontrol"]
bag_ok = sum(1 for b in bag if b["tamam"])
kontrol_n = sum(len(b["kontroller"]) for b in bag)
baski = d["baski"]
sigan = sum(1 for b in baski if b["sigar"])
destek = sum(1 for b in baski if b["desteksiz"])
ta = d["tarama"]
tmin, tmax = ta["serbest_tilt"]
pmin, pmax = ta["serbest_pan"]
TAR, PAR = K["tilt_aralik"], K["pan_aralik"]
tt, tp = d["tork"]["tilt"], d["tork"]["pan"]
r62 = d["r62"]
gr = d["grup"]
ev_cak = len(d["statik"])
bos_kp = min(v[0] for v in ta["bosluk_kafa_pan"].values())
bos_kp_a = min(ta["bosluk_kafa_pan"].items(), key=lambda kv: kv[1][0])
bos_kg = min(v[0] for v in ta["bosluk_kafa_govde"].values())
bag_min = d["bagil_bosluk"]["en_kucuk"][0] if d["bagil_bosluk"]["en_kucuk"] else [0, "-", "-"]
ms = tt["mesnet"]
OL = d["olcu"]

KARAR_TORK = ("**Tork:** tilt MG996R en kötü açıda %s kg·cm (yerçekimi %s + ivme %s; kafa grubu %s g, kütle merkezi tilt ekseninden %s mm) → "
              "pay %s×; pan MG996R %s kg·cm (atalet + rulman + kablo, tahmini profil) → pay %s×. İki eksende de mevcut MG996R yeterli; "
              "kafa ağırlığı ve devirme momenti pan'da iki 6808-2RS'de, tilt'te 625ZZ pim ile horn arasında paylaşılıyor."
              % (sayi(tt["toplam_kgcm"], 2), sayi(tt["yercekimi_max_kgcm"], 2), sayi(tt["ivme_kgcm"], 2), sayi(tt["kutle_g"], 0),
                 sayi(tt["am_eksen_mm"], 0), sayi(tt["pay"], 1), sayi(tp["toplam_kgcm"], 2), sayi(tp["pay"], 0)))
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

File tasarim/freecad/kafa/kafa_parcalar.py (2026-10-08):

# Kafa modulu (boyun + pan + tilt + kafa) - PARCALAR, kutle ve kinematik (FreeCAD 1.1, Part)
# Import edilebilir: kafa_montaj.py (kontroller + kayit); 2. asamada carpisma / ana montaj bunu kullanir.
# Koordinat (kafa yereli, arayuz.MODULLER["kafa"]): orijin = traversin ust yuzu ortasi (global 0, 975, 0), X sag, Y yukari,
# Z ileri. Pan ekseni yerel Y ekseni (x = z = 0), tilt ekseni X'e paralel (y = 130, z = 25). Ev pozu: duz bakis.
# Arayuz olculeri: ../arayuz.py KAFA. V3 kaynak: rc:782-800 (kafa grubu), rc:471-484 (head_shell 210x180x150),
# rc:636-642 (visor), rc:374-396 (7" LCD, kamera). Iskelet ve kabuk geometrisi degismez (kabuk ust kapakta R62 aciklik).
#
# Yapi
#   Govde (traverse sabit): boyun plakasi (3 mm Al; 2x M6 + cekic somun traversin ust kanalina) -> servo yuvasi (PETG;
#       pan MG996R'yi kulaklarindan tasir, M3 + isil gomme somun) -> rulman yuvasi (PETG; iki 6808-2RS, 4x M3 ile servo
#       yuvasina). Kafa kutlesi ve devrilme momenti 6808 ciftinde (ust rulman eksenel yuku tasir) -> pan servosu yalniz
#       dondurur. Servo yuvasinda arka kablo kanali + alt pencere (kablolar R62 halkasindan govdeye iner).
#   Pan (pan ekseninde doner): pan horn -> boyun mili (PETG; ici bos O32, alt diski horn'a 4x M3; 6808 ic bileziklerine
#       oturur, omuzu ust rulmanin ic bileziginde) -> egme catali (PETG; mil flansina 4x M3 + isil gomme somun) -> tilt
#       MG996R (govdesi catalda, mil +X) + karsi yatak pimi (625ZZ ic bilezigi M5 civatayla catalin sol duvarina sikilir).
#   Kafa (Pan * tilt): tilt horn -> kafa iskeleti (PETG; sag yanak horn'a 4x M3, sol yanakta 625ZZ dis bilezigi; ustte
#       kafa tablasi) -> on (yuz) ve arka kafa kabugu (tablaya 4x M3 ISO 7380 + isil gomme somun) -> 7" LCD (on kabukta
#       ekran yuvasi, 4x M3), siyah akrilik vizor (VHB bant), Camera Module 3 (on kabukta, 4x M2).
import os, sys, math, time

HERE = os.path.dirname(os.path.abspath(__file__))
UST = os.path.dirname(HERE)
for _p in (HERE, UST):
    if _p not in sys.path:
        sys.path.insert(0, _p)
from kafa_lib import *   # noqa
import arayuz as A

t0 = time.time()
K = A.KAFA
YT, ZT = K["tilt_nokta"][1], K["tilt_nokta"][2]      # tilt ekseni (130, 25)

# ---------------------------------------------------------------- olcu zinciri (Y: asagidan yukari, yerel)
Y_PL = K["boyun_plaka"]["t"]               # 3: plaka ust yuzu
Y_KULAK_T = 8.0                            # servo yuvasi kulak (flans) ust yuzu
Y_PK = 41.6                                # pan servosu kasa ustu (taban 5,0 -> plakaya 2 mm)
Y_PT = Y_PK - MG["H"]                      # 5.0
Y_EAR = (Y_PK - MG["TAB_TOP"] - MG["TAB_T"], Y_PK - MG["TAB_TOP"])   # 31.6 / 34.1 kulak yuzleri
Y_LEDGE0 = Y_EAR[0] - 7.0                  # 24.6 kulak tablasi alti (7 mm: M3 isil gomme somun 5,7)
Y_BLK = 46.0                               # servo yuvasi ust yuzu = rulman yuvasi alt yuzu
Y_HORN = (Y_PK + HORN_MG["Z0"], Y_PK + HORN_MG["Z1"])   # 44.6 / 47.9
Y_DISK = (Y_HORN[1], Y_HORN[1] + 5.0)      # 47.9...52.9 boyun mili alt diski
Y_PEN = (53.0, 63.0)                       # boyun mili kablo penceresi
Y_R1 = (64.0, 71.0)                        # alt 6808
Y_R2 = (75.0, 82.0)                        # ust 6808 (eksenel yuk)
Y_UST = Y_R2[1]                            # 82 rulman yuvasi ust yuzu
Y_OMUZ = (82.0, 84.0)                      # mil omuzu (ust rulman ic bileziginde)
Y_KONI = (84.0, 92.0)                      # 45 derece gecis
Y_FL = (92.0, 96.0)                        # mil flansi (catal civatalari)
Y_CB = (96.0, 99.0)                        # catal tabani
R_CAP = 30.0                               # rulman yuvasi dis yaricapi
R_ODA = 27.5                               # kablo odasi (halka) ic yaricapi
X_TB = -12.7                               # tilt servosu taban yuzu (mil +X)
X_TK = X_TB + MG["H"]                      # 23.9 kasa ustu
X_TH = (X_TK + HORN_MG["Z0"], X_TK + HORN_MG["Z1"])   # 26.9 / 30.2 tilt horn
X_TKUL = (X_TB + 26.6, X_TB + 26.6 + MG["TAB_T"])     # 13.9 / 16.4 kulak yuzleri
X_EP = (X_TKUL[0] - 5.0, X_TKUL[0])        # 8.9...13.9 catal kulak plakasi
X_SAG = (X_TH[1], X_TH[1] + 5.0)           # 30.2...35.2 sag yanak (horn'a bagli)
X_SOL = (-35.2, -24.2)                     # sol yanak (625ZZ yuvasi)
X_RUL = (-29.2, -24.2)                     # 625ZZ
X_DUVAR = (-23.2, -13.2)                   # catal sol duvari (M5 isil gomme somun)
Y_TABLA = (178.0, 183.0)                   # kafa tablasi
KB = K["kafa_kutu"]                        # 210 x 180 x 150
KX, KY0, KY1 = KB[0] / 2, K["kafa_alt_y"], K["kafa_alt_y"] + KB[1]          # 105, 95, 275
KZ0, KZ1 = 10.0 - KB[2] / 2, 10.0 + KB[2] / 2                               # -65, 85 (rc: merkez z 10)
KT = 2.5                                   # kabuk duvari (rc:472 V3 2,5)
Z_DIKIS = 30.0                             # on / arka kabuk ayrimi (LCD arkasi 64,5)
Z_LCD = KZ1 - KT - 3.0                     # 79.5 LCD panel on yuzu (3 mm ekran yuvasi kenari onunde)
Y_LCD = KY0 + 84.0                         # 179 LCD merkezi (rc:790)
Y_CAM = 258.0                              # kamera lens ekseni (LCD kulaklarinin 17 mm ustu; rc 247 LCD kulagiyla cakisirdi)
Z_CAM = Z_LCD - LCD["panel_t"] - LCD["arka_t"] + 1.6   # 76.0 kamera PCB on yuzu (LCD kulak on yuzu ile ayni)
ACIKLIK = dict(x=42.0, z=(-56.0, 64.0), r=15.0)          # kafa alt duvarinda boyun acikligi (kafa_montaj taramasi)

assert abs(K["pan_nokta"][1] - Y_HORN[0]) < 1e-9 and abs(K["tilt_nokta"][0] - X_TH[0]) < 1e-9
assert abs(KY1 - A.HEAD_UP) < 1e-9


def gp(local, m):
    return m.multVec(V(*local))


M_P = matris((1, 0, 0), (0, 0, -1), (0, 1, 0), (0, Y_PK, 0))        # pan servosu: mil +Y, govde one (+Z)
M_T = matris((0, 1, 0), (0, 0, 1), (1, 0, 0), (X_TK, YT, ZT))       # tilt servosu: mil +X, govde arkaya (-Z)

P = []


def add(ad, grup, shape, tur, malzeme, kod=None, renk="gri", patlat=(0, 0, 0), not_="", doluluk=None):
    P.append(dict(ad=ad, grup=grup, shape=shape, tur=tur, malzeme=malzeme, kod=kod or ad, renk=renk,
                  patlat=list(patlat), not_=not_, doluluk=doluluk))
    return len(P) - 1


BAG = []     # baglanti tanimlari (kafa_montaj kontrol eder)
EP_G = (0, -40, 0)       # patlatma: govde asagi
EP_P = (0, 40, 0)
EP_K = (0, 140, 0)
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

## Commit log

2026-09-27 Tekerlekli insansı robot: fizibilite, plan, CAD ve tasarım demosu
    [Humanoid-Robot-Montaj.step, parca-listesi.csv]
2026-10-05 Demo V2 ve V3: hoca geri bildirimi, yeni ekranlar, V2/V3 STEP ve parça listeleri
    [Humanoid-Robot-Montaj-V2.step, Humanoid-Robot-Montaj-V3.step, Humanoid-Robot-Montaj.step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]
2026-10-07 FreeCAD'e gecis: datasheet'ler, sigma testi ve 2 eksenli omuz modulu
    - donanim/datasheet: elde olan Pi 5 ve Nextion NX1060P101_011 belgeleri + ozet
    (buyuk uretici dosyalari .gitignore'da, adresleri README'de)
    - tasarim/freecad/sigma: 40x40 agir sigma test parcasi
    - tasarim/freecad/omuz: sag omuz (one-arka + yana acma) + ust kol baglantisi,
    70 parca, tum baglanti elemanlari; carpisma taramasi, tork, BOM, rapor.html
    [kol-catali.stl, omuz-gobegi.stl, omuz-montaj.FCStd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]
2026-10-07 FreeCAD: arayuz.py, ortak kutuphane, iskelet modulu ve moduller arasi carpisma kontrolu
    - arayuz.py: V3 olculeri, modul yerlesimleri, ayrilmis bolgeler (tek kaynak)
    - ortak_lib.py: genel baglanti elemanlari ve dogru sigma kesiti
    - omuz arayuzden okuyor; regresyon 16/16 olcutte fark 0
    - iskelet: 59 parca, 0 carpisma, 12/12 baglanti oturuyor, 5,79 kg
    - carpisma.py: iskelet + sag/sol omuz, 2x875 poz, 0 carpisma
    [iskelet-bom.csv, iskelet-montaj.FCStd, iskelet-montaj.step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]
2026-10-07 FreeCAD: ana montaj (iskelet + sag/sol omuz, 7 eklem) ve eklem dogrulamasi
    - montaj/: robot-montaj.FCStd + STEP (195 parca), sol omuz gercek aynali
    - eklemler simulasyonla surulup dogrulandi (sapma ~1e-10), GUI'de surukleme calisiyor
    - carpisma.py tekrar: 2x875 poz, 0 carpisma; kutle 6,72 kg
    - rapor.html, hareket GIF'i, README montaj bolumu
    [robot-montaj.FCStd, robot-montaj.step]
2026-10-08 FreeCAD: kabuk modulu (govde + etek, X2D'ye bolunmus 15 baski parcasi)
    - kabuk/: govde 4 bant x2 + arka kapak, etek 3 bant x2; PETG 3 mm, desteksiz
    - Bambu Lab X2D hacmi resmi sayfadan (256x256x260); arayuz.YAZICI
    - omuz O84 delikleri, Nextion NX1060P101 yuvasi, iskelete 10 braket
    - carpisma: kabuk ici/iskelet/bolge 0; kol-kabuk eklem araliginda 0 (min 5 mm)
    - montaj 11,65 kg, AM 429 mm; omuz ve iskelet regresyonu fark 0
    [kabuk-bom.csv, kabuk-montaj.FCStd, kabuk-montaj.step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]
2026-10-08 FreeCAD: dirsek modulu (dirsek + bilek + el, iki kol) ve kol zinciri taramasi
    - dirsek/: MG996R dirsek 0..105 (625ZZ + pim karsi yatak), bilek +-90, kanca el; 4 baski parcasi X2D'ye sigiyor, desteksiz
    - carpisma: kol basina 1755 poz + kol-kol 227 cift, eklem araliginda 0; en kucuk kol-kabuk 3,76 mm
    - ana montaj 503 parca, 14 eklem, 12,39 kg, AM 448 mm; eklem sapma ~1e-10
    - tork: yuksuz jest senaryosu (dirsek 6,1x, omuz 2,5x); el yuku ~50 g sinirli
    - omuz, iskelet, kabuk regresyonu fark 0
    [dirsek-bom.csv, dirsek-montaj.FCStd, dirsek-montaj.step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]
2026-10-08 FreeCAD: kafa modulu (pan/tilt boyun, yuz ekrani, kamera) ve kafa-kol taramasi
    - kafa/: MG996R pan -90..90 (2x 6808 rulman) + tilt -25..30 (625ZZ + pim), 7" LCD + vizor, kamera; 98 parca, 7 baski parcasi X2D'ye sigiyor, desteksiz
    - carpisma: kafa <-> kabuk/iskelet/omuz 0; kafa <-> kol 144 poz cifti (el yuzun onunde) -> yazilim yasak bolgesi
    - ana montaj 601 parca, 13,75 kg, AM 514 mm; eklem sapma ~1e-10
    - regresyon omuz/iskelet/kabuk/dirsek fark 0; kabuk raporu yeniden uretildi
    - carpisma-sonuc.json birlestirilmis (tam kosu kafa bolumunde bellekten durdu)
    [kafa-bom.csv, kafa-montaj.FCStd, kafa-montaj.step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]
2026-10-08 FreeCAD: taban modulu, bolumlu tam carpisma taramasi ve robot ozeti
    - taban/: alt plaka + 2 kat (lazer, DXF), 4x JGB37 + teker, aku, guc elektronigi, Pi 5/ESP32/PCA, sonar, acil stop; 4 baski parcasi
    - tam robot 907 parca, 22 eklem, 21,66 kg (kablo payi dahil), AM 375 mm; devrilme payi >= 2,9x
    - carpisma.py bolumlu (carpisma_kos.py), tek kosu: eklem araliginda yalniz kafa-kol yasak bolgesi (yazilim sinirlariyla), taban 0
    - kafa yasak bolgesi 5 derece hassasiyetle netlestirildi
    - OZET.md: modul, kutle, devrilme, motor, aku, tum yazilim sinirlari, acik isler
    [alt-plaka-3mm-al.dxf, elektronik-kati-on-5mm-kontrplak.dxf, guc-paneli-arka-5mm-kontrplak.dxf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]
2026-10-26 Sesli mod: SesTetik/VAD, Vosk, sohbet hafizasi; etkilesim gunlugu, STT test seti, icerik denetleyici, systemd; ESP32 firmware + jest kutuphanesi (104 test)
2026-10-26 Pi 5 kurulum kaydi, mikrofon secim raporu, Pi 5 kutu STL/betik; README ve CLAUDE.md haritasi (26 Ekim 2026)
    - kod/PI5-KURULUM.md: lale Pi'sinin durumu, baglanma/calistirma komutlari, sifirdan kurma (cloud-init + Imager CLI), tuzaklar, acik isler
    - raporlar/mikrofon-secimi.md: gurultu bastirmali mikrofon karsilastirmasi; karar XVF3800 dizi + yonlu mikrofon
    - tasarim/pi5-kutu/: taban + standart/fanli kapak STL, parametrik pi5_kutu.py, baski notu, onizlemeler
    - README klasor tablosu ve acik isler; CLAUDE.md yazilim tablosu ve Pi'de dogrulananlar
2026-10-27 Konum paketi: Wi-Fi parmak izi, GPS, BLE, ArUco, gorsel yer ogrenme, odometri, elle bolge + birlestirici; bolgeye gore tarif ve yonlu isaret; ESP32 odo telemetrisi, odo_sifirla, IMU iskeleti, jest yo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
2026-10-27 Lale: cevap varyantlari, bilinmeyen soru raporu, bakim modu, konum test turu, gurultu provasi, yuz ifadeleri/bakis; ESP32 yonlu isaret jesti (sol kol ayna, ileri/arka; firmware 0.3.0); 219 test
2026-10-27 Lale: telefondan kumanda (kod/robot/uzaktan: stdlib HTTP sunucu, PIN, D-pad/jest/soyle/bolge/bakim, olu adam), 16 test
2026-10-27 Harita: README/CLAUDE.md ikinci tur (bakim, olcum betikleri, telefon kumandasi, ESP32 yonlu jest, 235 test)
2026-10-29 Kopru: 29.10 kararları — yazılımı etkileyenler (ivme ≤ 0,1, rampada kollar ev pozu, tilt ±13, el yükü ~100 g)
    Kaynak: lale-duzeltme planlama/kararlar-2026-10-29.md ve planlama/y2/Y2a-kontrol.md.
    F2 (tilt) ve F8 (hareket sınırları) satırları ile taban/akü satırı güncellendi.
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2026-10-29 servolar.cpp: guc yorumu 10 servo / uc hat (A sag kol, B sol kol, C kafa), DS3235
2026-11-14 Pi: ESP32 0.5.0 guc/role sozlesmesi (arm, birak, reset, guc olayi) ve resetsiz port acilisi
    - seri.py: port_ac DTR etkin + RTS birakik acar, acinca DTR'yi birakir (pyserial once
    DTR sonra RTS ayarlar; eski sira arada EN'i LOW yapiyordu). esp32_reset(ser) ve
    SeriBaglanti.esp32_reset: DTR birakik, RTS 100 ms, sonra hazir bekler.
    - SeriProtokol: arm/birak/reset/ping; satir_oku -> satir_isle kancasi guc, neden, ariza,
    acil, bara, aku, son_ret tutar; hazir_bekle surekli okuyucu varken satir calmaz.
    SahteSeri gucu taklit eder. kapat yalniz dur gonderir, birak gondermez.
    - konum: seri okuyucu odometri kapaliyken de calisir ve okuyucu olarak kaydolur;
    konum kapaliysa ana.main seri.okuyucu_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
